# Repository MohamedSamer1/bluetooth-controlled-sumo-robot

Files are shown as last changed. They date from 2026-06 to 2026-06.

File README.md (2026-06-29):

<p align="center">
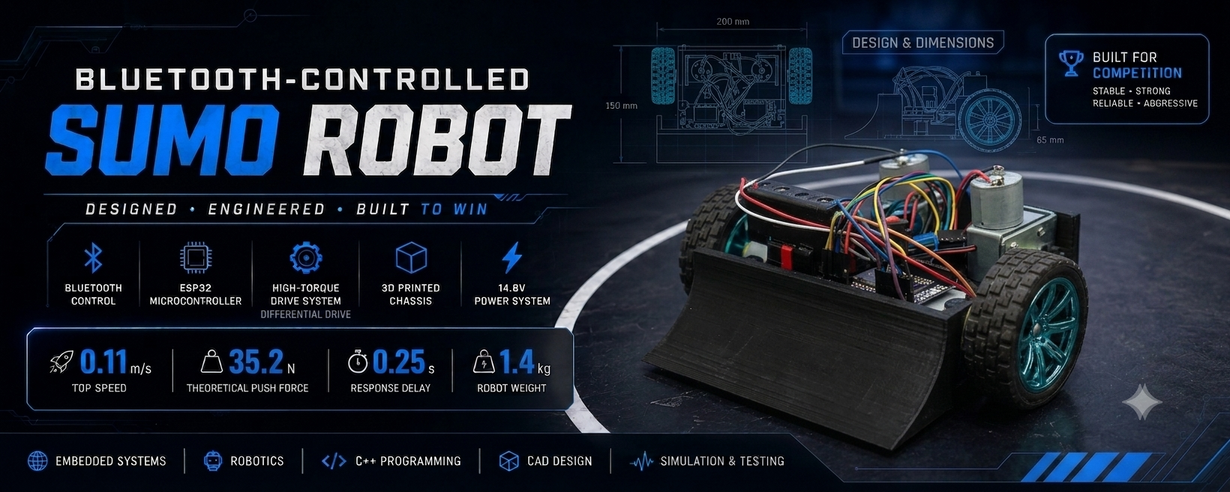
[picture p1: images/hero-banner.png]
Bluetooth-Controlled Sumo Robot
    
</p>

<h1 align="center">🤖 Bluetooth-Controlled Sumo Robot</h1>

<p align="center">
A high-performance ESP32-powered sumo robot engineered for competitive robotics.<br>
Designed through a complete engineering workflow spanning mechanical design,
embedded systems, electronics integration, mathematical modeling, and system validation.
</p>

<p align="center">









</p>

---

## 📑 Table of Contents

- [Project Overview](#-project-overview)
- [Design Objectives & Requirements](#-design-objectives--requirements)
- [System Architecture](#️-system-architecture)
- [Mechanical Design](#️-mechanical-design)
- [Electronics Design](#-electronics-design)
- [Control System & Software](#-control-system--software)
- [Engineering Calculations](#-engineering-calculations)
- [CAD Gallery](#️-cad-gallery)
- [Simulation & Validation](#-simulation--validation)
- [Final Prototype & Specifications](#-final-prototype--specifications)
- [Results & Lessons Learned](#-results--lessons-learned)
- [Challenges & Engineering Decisions](#-challenges--engineering-decisions)
- [Future Improvements](#-future-improvements)
- [Repository Structure](#-repository-structure)
- [References](#-references)
- [Team](#-team)
- [License](#-license)

---

## 📖 Project Overview

Sumo robotics combines mechanical engineering, embedded systems, electronics, and control theory to build robots capable of pushing opponents out of a circular arena while maintaining stability, traction, and responsiveness.

This project was developed for the **Mechatronics Design** course at **Modern Sciences and Arts University (MSA University)**. Rather than treating the build as a programming exercise alone, the team followed a full engineering design process — concept development, analytical calculations, CAD modeling, electronics integration, firmware development, simulation, manufacturing, and experimental testing — to produce a fully functional Bluetooth-controlled sumo robot.

**Project summary:**

- **Controller:** ESP32, communicating wirelessly with a smartphone over Bluetooth
- **Locomotion:** Differential drive using two independently controlled DC motors
- **Chassis:** Low-profile wedge design that maximizes pushing capability
- **Workflow:** Mechanical CAD (Inventor) → circuit design (Proteus/KiCad) → firmware (Arduino) → analytical modeling (MATLAB/Simulink) → physical assembly and testing

The final prototype achieved stable wireless control, fast motor response, and competitive maneuverability, meeting all project design objectives.

---

## 🎯 Design Objectives & Requirements

The goal was to design and manufacture a compact, reliable, high-performance Bluetooth-controlled sumo robot. This translated into the following engineering targets:

| Requirement | Goal |
|---|---|
| Bluetooth communication | Stable, low-latency link between phone and robot |
| Pushing force | Maximized without sacrificing stability |
| Center of gravity | Kept as low as possible |
| Footprint | Compact, arena-appropriate dimensions |
| Response time | Minimal delay between command and motion |
| Drive system | Reliable differential-drive control |
| Maintainability | Modular assembly for easy access/repair |
| Structure | Robust enough to withstand collision loads |

Every mechanical, electrical, and software decision in this project was evaluated against this table to keep the three subsystems working as one coherent mechatronic system.

---

## 🏗️ System Architecture

The robot is organized into four subsystems that map directly onto the signal/power flow from operator to motion:

```text
Smartphone → Bluetooth → ESP32 → Motor Driver → DC Motors → Robot Motion
```

| Subsystem | Contents |
|---|---|
| **Mechanical** | Custom CAD chassis, low-profile wedge, differential-drive wheel layout, optimized weight distribution |
| **Electrical** | ESP32 microcontroller, L298N motor driver, Li-ion battery pack, DC geared motors, Bluetooth module |
| **Software** | Arduino firmware, Bluetooth protocol handling, differential-drive control logic, PWM motor control |
| **Validation** | MATLAB calculations, Simulink modeling, Proteus circuit simulation, physical testing |

> 💡 **Engineering focus:** mechanical design, electronics, embedded programming, simulation, and validation were developed together — not bolted on sequentially — to produce a balanced, competitive platform.

---

## ⚙️ Mechanical Design

### Design Philosophy

Every mechanical component was chosen or shaped around three priorities: maximize pushing capability, keep the center of gravity low, and minimize weight without sacrificing rigidity.

### Chassis & Wedge

The chassis was modeled in **Autodesk Inventor** using a modular approach for easier manufacturing, assembly, and maintenance. Key considerations:

- Low-profile geometry that can slide underneath an opponent's chassis
- Compact footprint for maneuverability
- Symmetrical weight distribution
- Easy access to internal electronics
- Rigid construction to absorb impact loads

The front **wedge** — one of the most important parts on any sumo robot — is angled to lift the opponent's front wheels, reduce their traction, transfer pushing force efficiently into the chassis, and shield the robot from direct frontal impacts. The attack angle balances engagement against ground clearance during normal movement.

<p align="center">
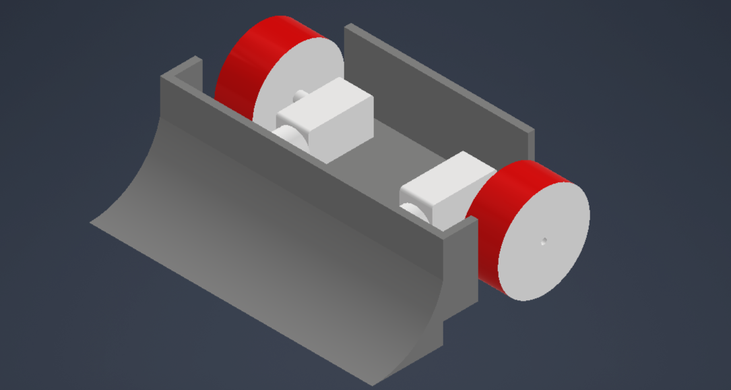
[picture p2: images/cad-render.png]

</p>

> **Figure 1:** Complete CAD assembly of the Bluetooth-Controlled Sumo Robot.

<p align="center">
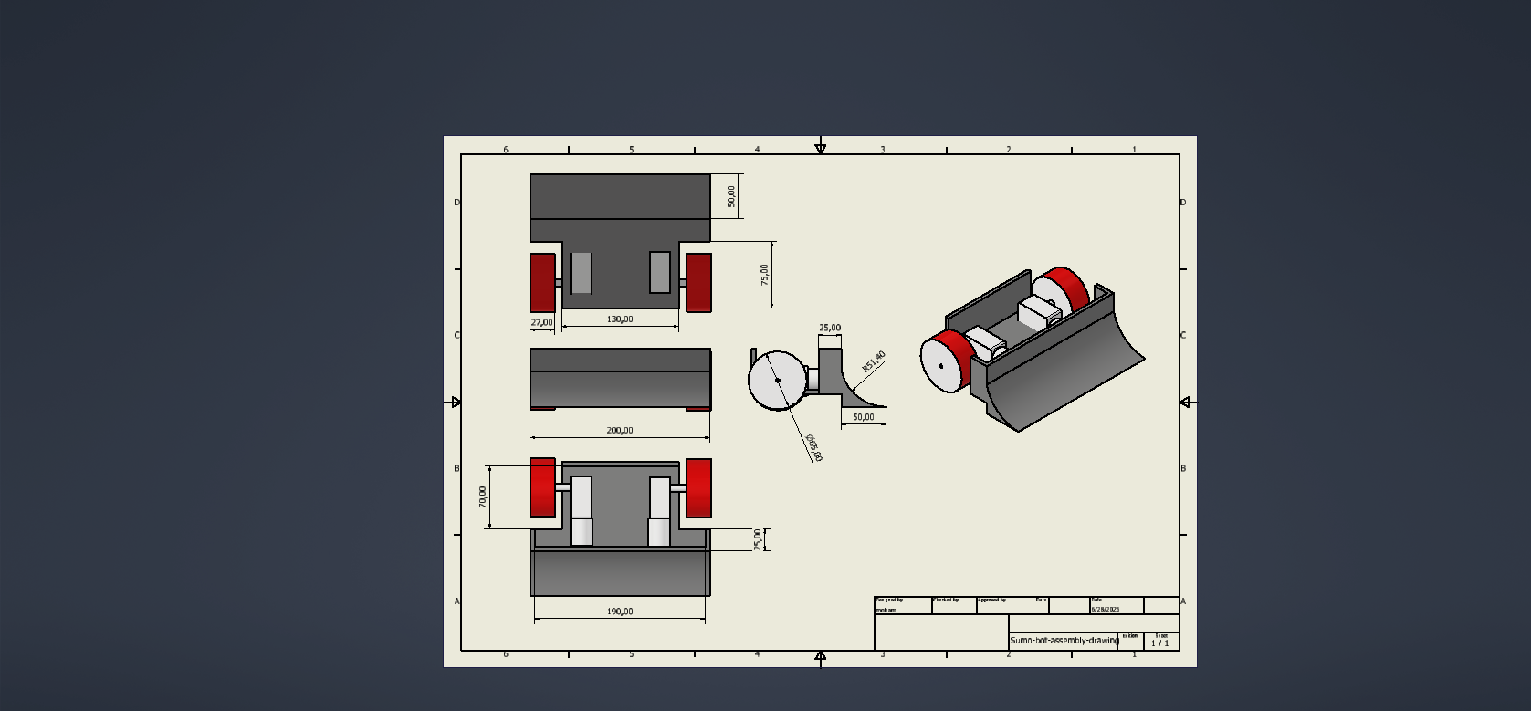
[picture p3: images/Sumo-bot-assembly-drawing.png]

</p>

### Wheel Configuration & Weight Distribution

The robot uses a **differential-drive** layout: two independently driven DC motors with high-traction wheels, plus one free-rotating caster wheel. This gives zero-radius turning, a simple control architecture, and reliable navigation inside the arena.

Weight distribution is just as critical as the drivetrain itself. The battery pack sits close to the drive wheels to increase normal force on the tires (improving traction and pushing force), and the heaviest components — motors and battery — are mounted as low as possible to keep the center of gravity down and improve stability during aggressive pushing.

<p align="center">
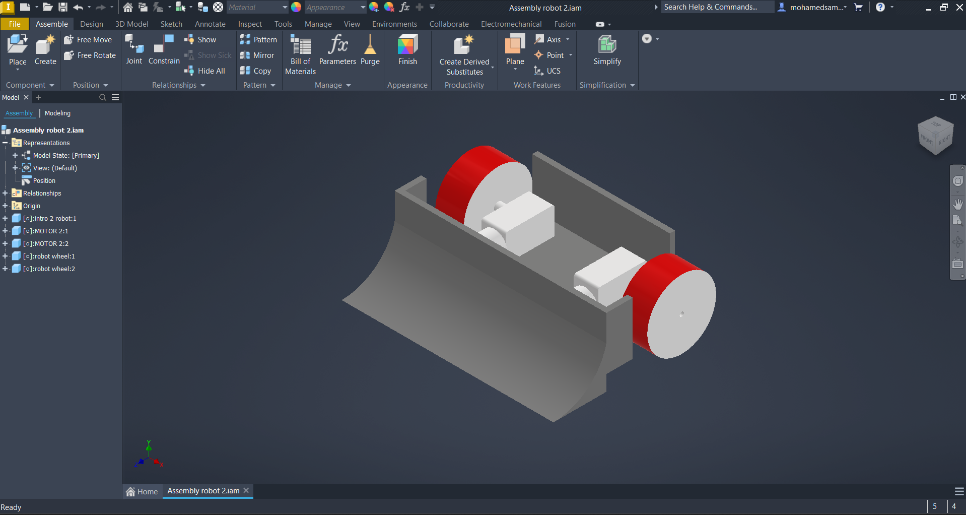
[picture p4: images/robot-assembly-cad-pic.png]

</p>

> **Figure 2:** Exploded view of the mechanical assembly.

---

## 🔌 Electronics Design

The electrical system covers four functions: control, power, motor drive, and communication.

| Component | Function |
|---|---|
| ESP32 | Main controller — reads Bluetooth input, generates PWM, coordinates drive logic |
| L298N Motor Driver | Bidirectional, PWM-based dual H-bridge motor control |
| DC Geared Motors | Robot propulsion |
| Li-ion Battery Pack | Power supply |
| Bluetooth Module | Wireless link to smartphone |

```text
Smartphone → Bluetooth → ESP32 Controller → L298N Motor Driver → Battery-supplied Motors
```

**ESP32:** chosen for its built-in Bluetooth, ample processing headroom, low power draw, multiple PWM outputs, and mature Arduino ecosystem support. It handles Bluetooth command parsing, PWM generation, motor direction control, and differential-drive coordination.

**Motor driver (L298N):** provides bidirectional control, PWM speed regulation, independent left/right channels, and high-current switching for both motors.

**Power system:** a rechargeable Li-ion pack sized to deliver stable voltage and sufficient current under heavy motor load, including the high startup current draw typical of DC motors. Sizing was checked analytically before parts were ordered (see [Engineering Calculations](#-engineering-calculations)).

**Circuit design:** the control circuit was first built and verified in **Proteus** to validate wiring and motor-control logic, then the schematic and PCB layout were finalized in **KiCad**.

<p align="center">
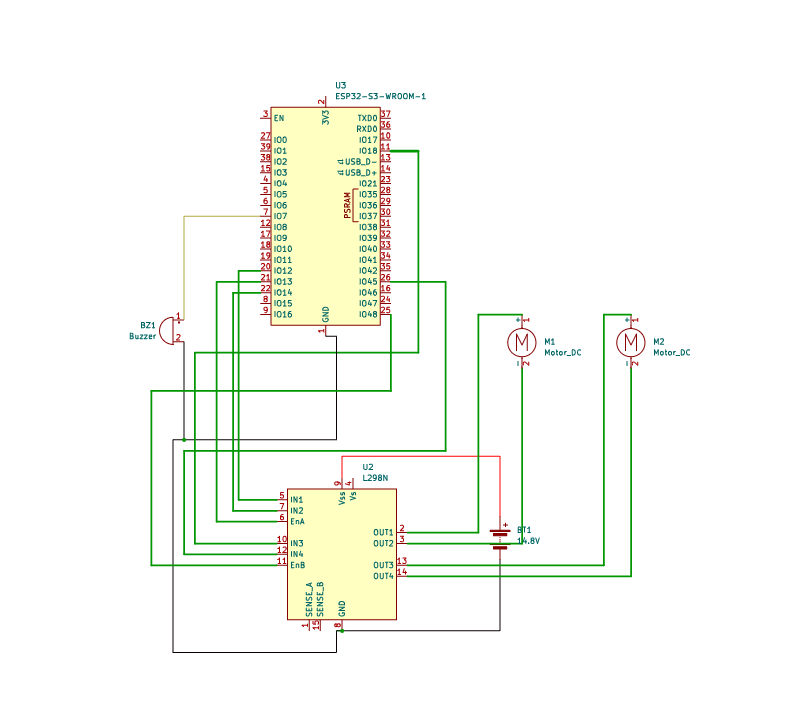
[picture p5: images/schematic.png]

</p>

> **Figure 3:** Electrical schematic of the control system.

---

## 🧠 Control System & Software

### Differential Drive Logic

The operator sends movement commands from a smartphone app over Bluetooth. The ESP32 parses each command and generates the matching PWM signals for the left and right motors:

| Left Motor | Right Motor | Resulting Motion |
|---|---|---|
| Forward | Forward | Forward |
| Reverse | Reverse | Backward |
| Forward | Reverse | Rotate right |
| Reverse | Forward | Rotate left |
| Stop | Stop | Stop |

### Firmware Architecture

Built in the **Arduino IDE** with a modular structure for readability, debugging, and future expansion:

```text
Initialize hardware → Connect Bluetooth → Receive command →
Process input → Generate PWM → Drive motors → Wait for next command
```

**Key features:**
- Wireless Bluetooth operation with low-latency response
- Differential-drive control algorithm
- PWM-based motor speed control
- Non-blocking firmware structure to keep communication responsive
- Modular code, ready for autonomous-navigation features later

---

## 📐 Engineering Calculations

Before any manufacturing began, the team ran the analytical work needed to size components correctly rather than relying on trial and error:

- Motor torque estimation
- Pushing-force analysis
- Robot velocity estimation
- Battery capacity and power-consumption calculations
- Differential-drive kinematics

These results directly drove the choice of motors, gear ratio, battery capacity, and overall mechanical layout. Full derivations are in **[`docs/Project_Report.pdf`](docs/Project_Report.pdf)**.

---

## 🖼️ CAD Gallery

The full robot was modeled in **Autodesk Inventor** before any physical fabrication, allowing the team to check component placement, weight distribution, assembly constraints, and manufacturability up front.

<p align="center">

</p>

> **Figure 4:** Complete CAD assembly.

<p align="center">
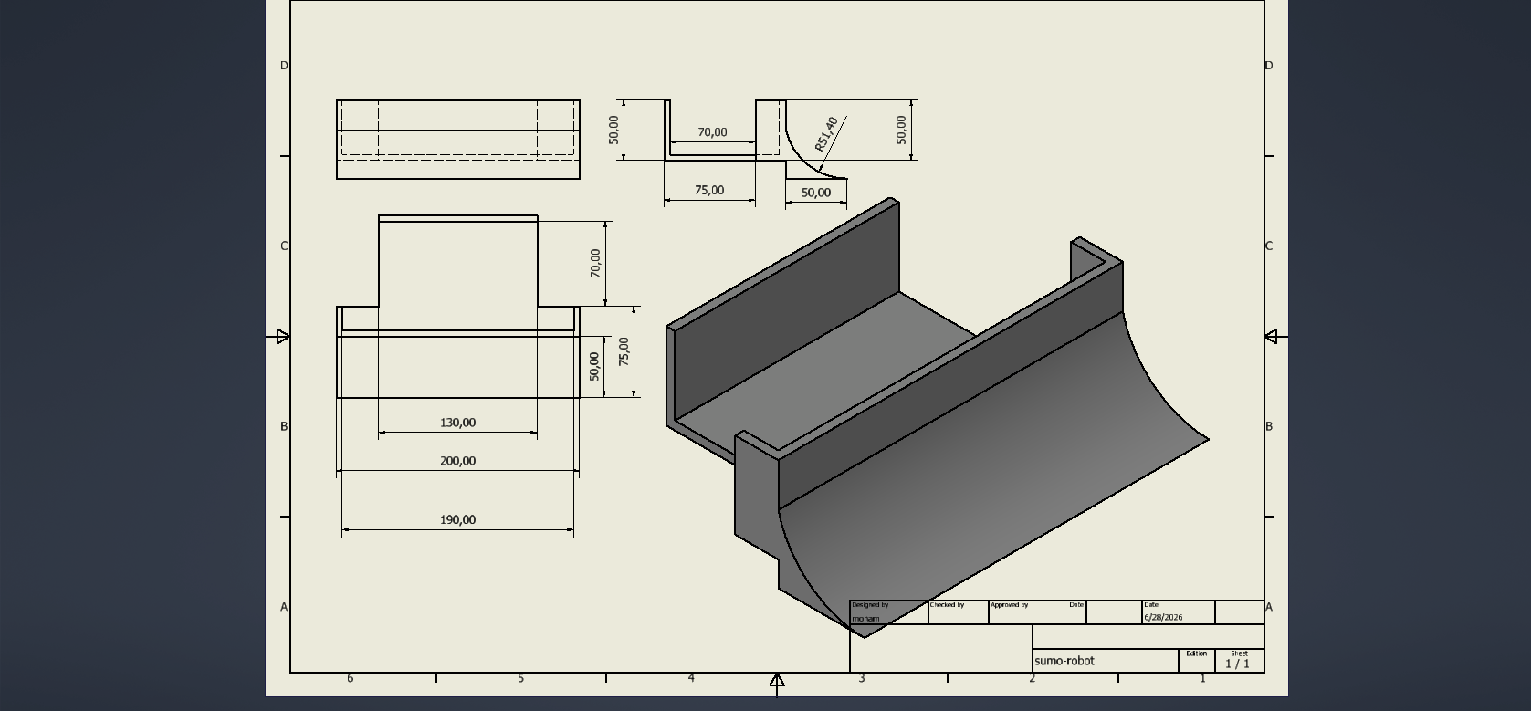
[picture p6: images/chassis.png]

</p>

> **Figure 5:** Chassis design — built for rigidity, low weight, and easy maintenance.

<p align="center">
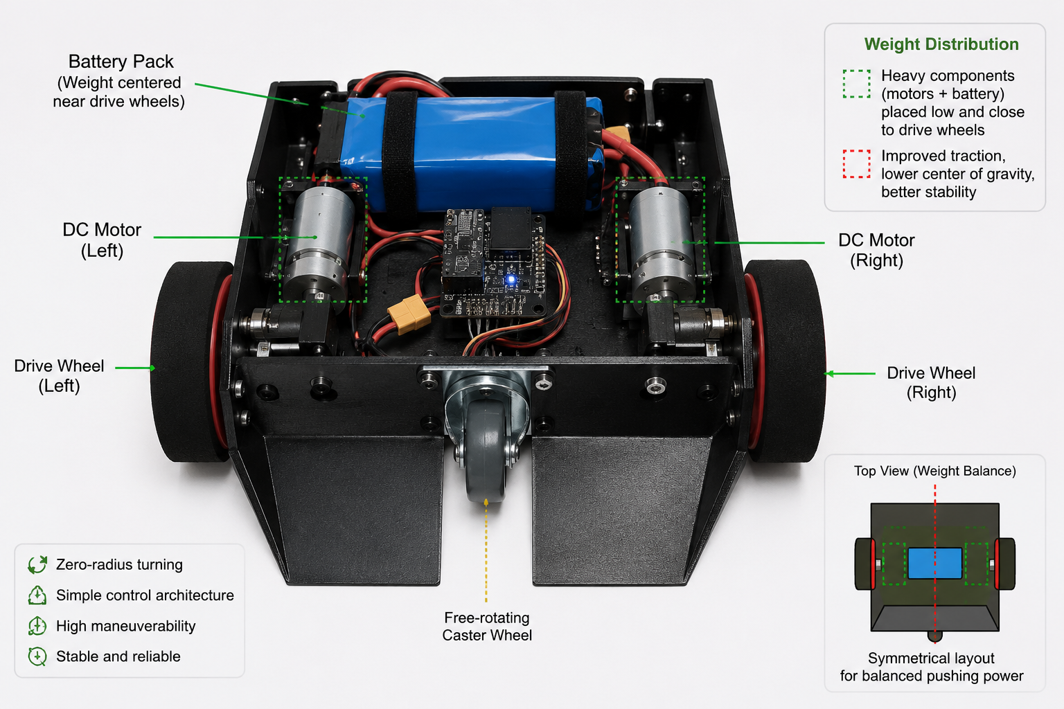
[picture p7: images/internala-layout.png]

</p>

> **Figure 6:** Internal electronics layout — planned to reduce cable clutter, improve accessibility, and keep weight balanced.

---

## 🧪 Simulation & Validation

### MATLAB & Simulink

Used to model the robot's dynamic behavior — differential-drive kinematics, motion response, and velocity estimation — and to cross-check the hand calculations above.

<p align="center">
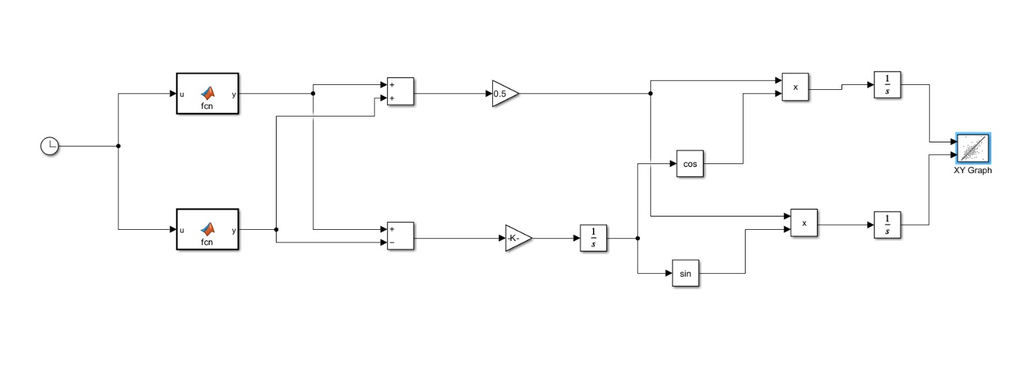
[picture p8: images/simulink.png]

</p>

> **Figure 7:** Simulink model used for system analysis.

### Proteus Simulation

The electronic control system (motor driver behavior, ESP32 control logic, wiring) was validated in **Proteus** before any hardware was assembled, catching circuit issues early and reducing rework.

<p align="center">
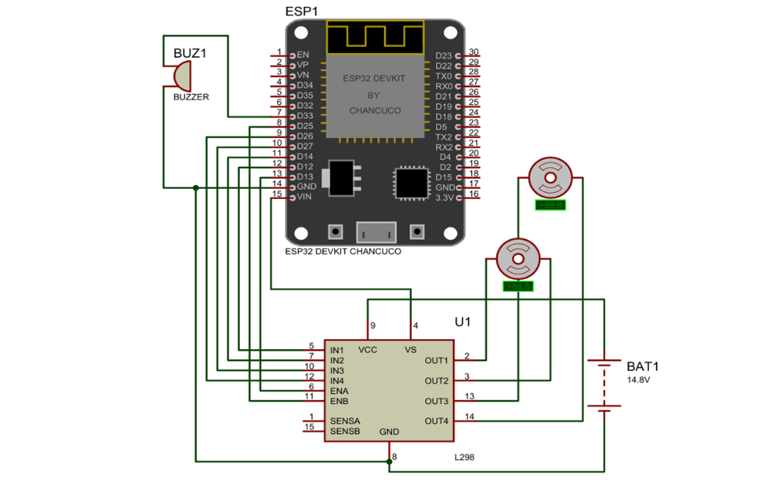
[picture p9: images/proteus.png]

</p>

> **Figure 8:** Proteus simulation of the electronic system.

---

## 🤖 Final Prototype & Specifications

After design, simulation, and validation were complete, the robot was manufactured and assembled into a fully functional prototype integrating all mechanical, electrical, and software subsystems.

<p align="center">
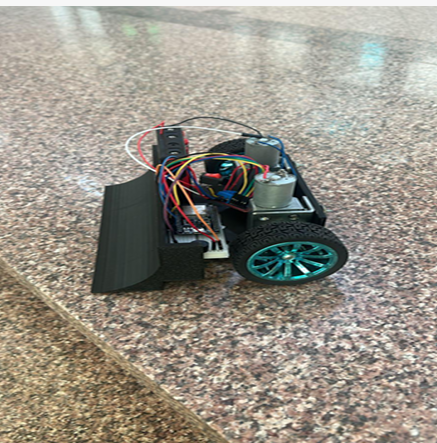
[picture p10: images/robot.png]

</p>

> **Figure 9:** Final assembled robot.

| Specification | Value |
|---|---:|
| Controller | ESP32 |
| Drive System | Differential drive |
| Communication | Bluetooth |
| Battery | 14.8V Li-ion |
| Motor Driver | L298N |
| Chassis | 3D printed |
| CAD Software | Autodesk Inventor |
| Simulation | MATLAB / Simulink |
| Circuit Validation | Proteus |
| **Top Speed** | **0.11 m/s** |
| **Theoretical Push Force** | **35.2 N** |
| **Response Delay** | **0.25 s** |
| **Robot Weight** | **1.4 kg** |

---

## 📊 Results & Lessons Learned

### Achievements

- ✅ Stable Bluetooth communication with low latency
- ✅ Responsive, stable differential-drive motion
- ✅ Compact, lightweight chassis with good traction
- ✅ Reliable electronic integration under motor load
- ✅ Simulation results consistent with physical testing

### Lessons Learned

- Mechanical and electrical systems need to be designed together, not in isolation — chassis geometry directly affects power and traction needs.
- Weight distribution has an outsized effect on pushing performance and stability.
- Simulating before manufacturing catches design errors early and saves rework.
- A modular firmware architecture made debugging and later changes much easier.
- Doing the analytical calculations up front, rather than after building, improved reliability and cut development time.

<p align="center">

| CAD Design | Prototype |
|---|---|
|  |  |

</p>

---

## 🚧 Challenges & Engineering Decisions

**Weight vs. traction:** more weight improves traction and pushing force but increases demands on motors and battery. The team kept the chassis lightweight overall while concentrating mass directly above the drive wheels — getting traction benefits without the full weight penalty.

**Center of gravity:** an elevated CG hurts stability during pushing contests. Mounting the battery and motors low and distributing mass symmetrically kept the robot stable during aggressive maneuvers.

**Startup current:** DC motors draw far more current at startup than during steady-state operation, so the battery and motor driver had to be sized for peak draw, not average draw, to guarantee reliable starts and stable voltage.

**Bluetooth responsiveness:** keeping the link responsive while continuously updating motor outputs required non-blocking firmware that avoids delays in the main control loop.

**Key decisions:**
- Differential drive chosen for simplicity and maneuverability over more complex steering systems
- ESP32 chosen specifically for integrated Bluetooth (avoiding a separate wireless module)
- CAD-first workflow adopted to catch manufacturing issues before cutting material
- Simulation completed before assembly to validate behavior ahead of physical testing

---

## 🚀 Future Improvements

| Area | Planned Enhancements |
|---|---|
| **Mechanical** | Aluminum/carbon-fiber chassis, improved wheel materials, adjustable wedge geometry, further weight reduction |
| **Electronics** | Custom PCB, higher-efficiency motor driver, battery monitoring, integrated voltage regulation |
| **Software** | PID speed control, closed-loop motor feedback, automatic braking, configurable drive modes |
| **Autonomy** | Ultrasonic/IR sensors, computer vision, line detection, obstacle avoidance, ROS 2 integration, autonomous opponent detection |

---

## 📁 Repository Structure

```text
bluetooth-controlled-sumo-robot
│
├── README.md
├── LICENSE
│
├── cad/
│   ├── MOTOR.dwg
│   ├── MOTOR.ipt
│   ├── robot-wheel.dwg
│   ├── robot-wheel.ipt
│   ├── Sumo-bot-assembly-drawing.dwg
│   ├── sumo-robot-body.ipt
│   └── sumo-robot.dwg
│
├── electronics/
│   ├── schematic.pdf
│   └── wiring.png
│
├── firmware/
│   ├── code/
│   ├── sumo-bot-code.ino
│   └── bluetooth-controlled-sumo-robot-simulink.slx
│
├── images/
│   ├── hero-banner.png
│   ├── cad-render.png
│   ├── chassis.png
│   ├── internala-layout.png
│   ├── MOTOR.png
│   ├── proteus.png
│   ├── robot-assembly-cad-pic.png
│   ├── robot-wheel.png
│   ├── robot.png
│   ├── schematic.png
│   ├── simulink.png
│   └── Sumo-bot-assembly-drawing.png
│
└── docs/
    └── Project_Report.pdf
```

| Directory | Description |
|---|---|
| `cad/` | Autodesk Inventor parts and drawing files |
| `electronics/` | Schematic (PDF) and wiring diagram |
| `firmware/` | ESP32 Arduino code and Simulink model |
| `images/` | CAD renders, prototype photos, and diagrams |
| `docs/` | Project report and supporting calculations |

---

## 📚 References

- ESP32 Technical Documentation
- Arduino Documentation
- Autodesk Inventor Documentation
- MATLAB & Simulink Documentation
- KiCad Documentation
- Proteus Documentation

Full derivations and design methodology are documented in **[`docs/Project_Report.pdf`](docs/Project_Report.pdf)**.

---

## 📄 License

Released under the **MIT License** — see [LICENSE](LICENSE) for details.

---

## ⭐ Support

If this project was useful or interesting:

- ⭐ Star this repository
- 🍴 Fork it and build your own version
- 💡 Open an issue with feedback or questions
- 🤝 Connect on LinkedIn

<p align="center">

### Built with ❤️ by Mohamed Samer
 **Mechatronics Engineering Student** · Modern Sciences and Arts University (MSA University)
 
 https://mohamed-samer.vercel.app/

</p>

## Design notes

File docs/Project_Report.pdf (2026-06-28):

# MSA

October University for Modern Sciences and Arts Faculty of Engineering
Department of Mechatronics System Engineering

# SUMO ROBOT

Prepared By

Jason Sameh Zarref | ID: 251086
Youssef Mohamed Mostafa | ID: 255000
Felobateer Akram Fawzi | ID: 255231
Ibrahim Wael Abdelmonem | ID: 251112
Mohamed Ahmed Imam | ID: 253440
Mohamed Samer | ID: 253335
Haneen Ahmed Nabih | ID: 251417

Supervisor
Dr. Amgad M. Bayoumy

SUMO Robot — Project Report

## Table of Contents

## Chapter 1: Introduction

### 1.1 Background

In recent years, robotics has become an increasingly accessible field due to advancements in microcontrollers, wireless communication, and compact power solutions. Educational and hobbyist robotics projects have gained popularity in academic environments and maker communities worldwide.

The SUMO Robot is a mobile robotic system designed to demonstrate fundamental principles of embedded systems, wireless control, and mechatronics integration. The core of the robot is an ESP-series microcontroller that processes input, executes control logic, and communicates with external devices. Acting as the intermediary between the microcontroller and physical motion is a motor driver, which supplies controlled current to two DC motors mounted on a two-wheel drive platform.

The power supply consists of four 3.7 V batteries connected to provide reliable voltage and current necessary for motor and controller operation. This combination of hardware allows the robot to move, respond to commands, and serve as a practical tool for learning and experimentation in robotics design.

### 1.2 Problem Definition

Despite the growing interest in robotics education, many existing mobile robotic kits are either overly expensive or lack flexibility for customization and real-world experimentation. Learners and hobbyists often encounter challenges when integrating wireless communication, motor control, and power management on a single platform. Specifically, problems include:

- Limited control precision: standard robot kits may not allow programmable control using open-source environments.
- Power inefficiency: some designs fail to provide stable power, leading to reduced motor performance or controller resets.
- Lack of integration: communication modules and motor control components are not always designed to work together seamlessly.
The SUMO Robot project addresses these issues by combining an ESP microcontroller, a dedicated motor driver, and a suitable battery system to create an affordable, adaptable, and efficient mobile robotic platform.

### 1.3 Functional Requirements

The SUMO Robot is designed to perform the following functions:

1. Wireless Command Reception — the robot must receive movement commands (e.g., forward, backward, turn) via a wireless interface supported by the ESP microcontroller.
2. Motor Control — the system must drive two DC motors using the motor driver, translating control signals into motion with appropriate direction and speed.
3. Stable Power Delivery — the battery pack must supply sufficient voltage and current to both the ESP controller and the motors without significant voltage drop during operation.

4. Directional Movement — the robot must be able to move forward, backward, turn left, and turn right using differential wheel control.
5. Robust Mechanical Design — the two-wheel drive base must support the robot's weight and maintain balance during motion.

### 1.4 Project Specification

Component | Specification
Controller | ESP-series microcontroller (e.g., ESP32 / ESP8266)
Motor Driver | Dual-channel motor driver (compatible with 2 DC motors)
Motors | 2 × DC motors (rated for low-voltage operation)
Wheels | 2 × compatible wheels
Power Supply | 4 × 3.7 V rechargeable batteries (lithium-ion or LiPo)
Communication | Wi-Fi / Bluetooth (based on the ESP module used)
Chassis | Lightweight platform supporting all components
Control Interface | Mobile app, web interface, or remote controller
Operating Voltage | Approx. 14.8 V (with appropriate regulation for ESP and motor driver)

Note: if needed, a voltage regulator or DC-DC converter can be used to match the ESP's operating voltage requirements.

### 1.5 Current Technology

Robotics platforms today range from simple educational kits to advanced autonomous systems. Common solutions in the current field include:

- Arduino-based robots: widely used in education, these robots use Arduino microcontrollers with basic motor shields for motion control. They are simple but can be limited in wireless capabilities without additional modules.
- Raspberry Pi robots: with a single-board computer at their core, these robots can perform complex processing and vision tasks but are often bulkier and require more power.
- ESP-controlled robots: the rise of ESP microcontrollers (such as ESP32 and ESP8266) has enabled low-cost robotic platforms with integrated Wi-Fi and Bluetooth, making remote control and IoT integration easier. They strike a balance between processing capability, power consumption, and connectivity.
- Commercial kits: products such as LEGO Mindstorms and VEX offer modular designs but at a higher cost and with limited openness for custom hardware/software extension.

Compared with these technologies, the SUMO Robot leverages the strengths of the ESP ecosystem, efficient power configuration, and a simple drive system to offer a flexible and affordable mobile platform suitable for learning, prototyping, and experimentation.

## Chapter 2: System Design

### 2.1 Discussion of Design

A DC motor was selected as the actuator for this project because it offers high starting torque, precise speed control, a compact size, and good performance across a range of load conditions.

An ESP32 was chosen as the microcontroller due to its low cost, high-performance dual-core processing, and built-in Bluetooth and Wi-Fi modules for wireless connectivity.

The system architecture connects the voltage source to the motor driver, which in turn supplies the two motors. The ESP32 microcontroller is connected wirelessly to a mobile phone, which sends the movement commands.

A 3D-printed chassis was used for the robot body. Although 3D printing costs more than a standard robot chassis, the resulting structure is significantly stronger. Similarly, rechargeable batteries were chosen over standard batteries; although more expensive upfront, they can be reused many times, making them more cost-effective over the project's lifetime.

### 2.2 Design Specification

Electrical

Operating voltage: 14.8 V. Battery life for the four batteries: approximately 20–30 minutes of continuous operation.

Mechanical

Footprint: 15 cm × 20 cm. Total weight: up to 1.5 kg.

Software

Bluetooth response time: between 40 ms and 150 ms. Programming language: C++.

### 2.3 System Outline

The robot's control architecture follows the signal path shown below: the mobile phone and the motor driver both feed information to the ESP32 controller, which processes this input and issues commands to the DC motors (the actuators). The motors then produce the physical output — the robot's motion.

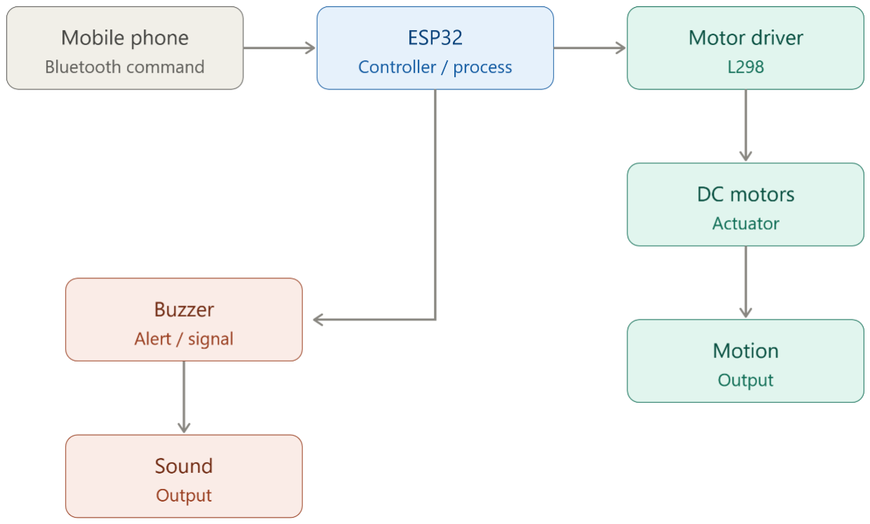
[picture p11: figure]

Figure 2.1 — System-level signal and control flow

## Chapter 3: Mechanical Design

The mechanical design of the robot is built around a differential-drive system powered by two high-torque DC motors. The chassis design prioritizes a low center of gravity and high traction to meet the requirements of the Sumo class.

### 3.1 Mechanical Design Calculations

The selection of the drive system was based on the need for high pushing torque and the ability to resist being pushed by opponents. The robot uses two miniature worm-gear DC motors rated at 12 V, with a gear ratio of 1:40 and a wheel diameter of 65 mm.

### 3.1.1 Torque and Pushing Force Analysis

The theoretical pushing force was calculated to confirm that the robot can overcome the friction of the dohyo (ring) and push opponents.

Motor specifications:

- Initial torque (TInitial) = 6.4 kg·cm
- Wheel radius (r) = 32.5 mm = 0.0325 m First, the torque is converted to SI units (newton-metres):

T_Initial = 6.4 kg·cm × 0.098 = 0.628 N·m T_Total = 2 × 0.628 = 1.256 N·m

The theoretical linear pushing force is then:

F_Push = T_Total ÷ r = 1.256 N·m ÷ 0.0325 m ≈ 38.6 N

So, the robot can push an opposing sumo robot of approximately 3 kg.

### 3.2 Mathematical Modeling

To implement precise control in the software, a mathematical model of the differential-drive system was established. This model relates the inputs (left and right wheel velocities) to the robot's pose in the global frame.

### 3.2.1 Differential Drive Kinematics

The robot's motion is defined by its position (x, y) and orientation (θ). The kinematic equations for the differential-drive system are derived below.

Let VR and VL be the linear velocities of the right and left wheels, and let L be the track width (the distance between the wheel centres).

Linear velocity of the robot (V):

V = (vR + vL) / 2

Angular velocity of the robot (ω):

The rate of rotation is determined by the difference in wheel speeds divided by the track width (L):

ω = (vR − vL) / L

## Chapter 4: Electrical Design

This chapter presents the electrical design of the proposed system and explains how electrical power is generated, distributed, and utilized to ensure proper system operation. It focuses on the selection of electrical components, the configuration of the power supply, and the calculations required to guarantee reliable and safe performance.

The electrical system plays a critical role in operating the control unit and driving the DC motors through a suitable motor driver. Special consideration is given to both normal operating conditions and peak-load situations, such as motor startup and stall conditions, to ensure that all components function within their specified limits and that the overall system operates efficiently and safely.

### 4.1 Power Supply Calculations

Battery Configuration

The system is powered using four lithium-ion batteries, each with a nominal voltage of 3.7 V. The batteries are connected in series to increase the total output voltage. The resulting nominal supply voltage is:

V_total = 3.7 V × 4 = 14.8 V

Voltage Regulation

The DC motors are rated for 12 V, but the L298 motor driver typically introduces a voltage drop of around 2–4 V; the motors therefore operate close to their rated capability rather than at the full battery voltage. The ESP32 operates at 3.3 V internally but accepts a 5 V input and regulates it internally.

Current and Power Requirements

The current consumption of the electrical components is estimated based on datasheet values and typical operating conditions.

Motor current (normal operation). Each DC motor has a rated current of 0.3 A at 12 V. Since two motors are used:

I_motors = 0.3 A × 2 = 0.6 A

The rated electrical power consumed by the motors is:

P_motors = V × I = 12 V × 0.6 A = 7.2 W

Motor current (stall condition). The stall current of each motor is 2 A. Under worst-case conditions:

I_stall = 2 A × 2 = 4 A

The maximum power drawn during stall conditions is:

P_stall = 12 V × 4 A = 48 W

Stall conditions are considered transient and are avoided during normal operation through appropriate control logic.

ESP32 and logic circuit consumption. The ESP32 microcontroller draws a current of approximately 240 mA during normal operation. The L298 motor driver also requires a small current for its internal logic circuits, approximately 40 mA. The total current required by the control and logic circuits is therefore:

I_logic = 0.24 A + 0.04 A = 0.28 A

This current is supplied through a regulated low-voltage power source to ensure stable and reliable operation of the control electronics.

Total Current Requirement

Under normal operating conditions:

I_total = I_motors + I_logic = 0.6 A + 0.28 A = 0.88 A

Applying a safety factor of 30%:

I_required = 0.88 A × 1.3 ≈ 1.15 A

The battery pack and power-distribution system are therefore designed to safely supply currents exceeding this value.

### 4.2 Electrical and Electronics Calculations

The DC motor is the main actuator in this system. To control the motor's speed and direction, an L298 dual H-bridge motor driver is used as the interface between the ESP32 microcontroller and the DC motors.

Section 4.1 established the system's current and power budget from first principles. This section verifies that the selected L298 driver can meet that budget at the component level.

From the motor datasheet, the rated current of each motor under normal load is 0.3 A at 12 V, giving a combined rated current of 0.6 A and a rated power of 7.2 W (as calculated in Section 4.1). Under stall conditions, each motor draws up to 2 A, giving a combined stall current of 4 A and a peak power draw of 48 W.

The L298 motor driver is rated to supply a maximum continuous current of 2 A per channel. Since each motor is driven on its own channel, the driver comfortably meets the 0.3 A normal-operation requirement per motor, and can also tolerate the 2 A per-motor stall current for short durations without exceeding its rated limit. Continuous operation at stall current is avoided in the control logic to prevent overheating and long-term damage to the driver.

Combined with the ESP32's 240 mA draw, the total system current requirement of approximately 0.88 A (1.15 A with a 30% safety margin, as derived in Section 4.1) falls well within the supply capability of the four-cell 14.8 V battery pack regulated through the L298 driver.

## Chapter 5: Control Design

The control design of the differential-drive sumo robot defines how sensory information is processed and translated into motor commands to achieve stable, responsive, and competitive motion. The robot follows a differential-drive configuration, where two independently driven wheels allow linear and rotational movement through velocity control. The control system integrates mathematical modeling, algorithm development, and mechatronic simulation to validate system performance before physical implementation. Detailed calculations, parameter tuning, and implementation code are provided in the appendices.

### 5.1 Simulation of Mathematical Modeling (Simulink)

The mathematical model of the differential-drive sumo robot was developed to describe the kinematic behaviour of the system and to predict its motion under various control inputs. The model is based on the differential-drive kinematics derived in Section 3.2, where the robot's linear and angular velocities are functions of the left and right wheel angular velocities.

Using MATLAB/Simulink, a dynamic simulation environment was created to represent the robot's motion in a two-dimensional plane. The model incorporates wheel radius, wheelbase distance, motor angular velocity, and robot orientation. By simulating different velocity inputs, the robot's forward motion, turning behaviour, and rotational response were analysed.

The Simulink model enabled verification of the control strategy by observing position, orientation, and velocity responses over time. This simulation step ensured that the control logic produced stable motion and correct turning behaviour before implementation in hardware.

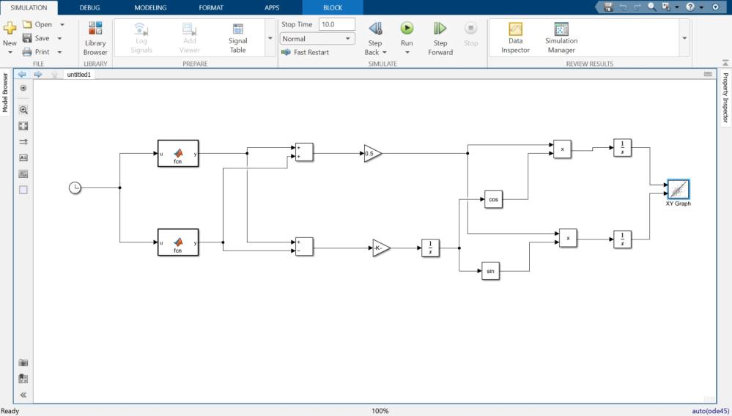
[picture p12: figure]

Figure 5.1 — Simulink block diagram of the differential-drive kinematic model

### 5.2 Control Algorithm (Flowchart)

The control algorithm governs the robot's decision-making process and movement strategy during operation. It is designed to process Bluetooth command input, determine the robot's current state, and generate the appropriate motor commands for navigation and opponent interaction.

The algorithm begins with system initialization, followed by continuous polling for an incoming Bluetooth command. Once a command is received, conditional logic determines whether the robot should move forward, move backward, or turn, and motor speed and direction are updated accordingly to achieve the desired motion.

A flowchart representation was used to clearly define the logical sequence and decision branches of the control algorithm, improving clarity, debugging, and future modification. The complete flowchart is shown below, and the corresponding implementation is provided in Appendix D.

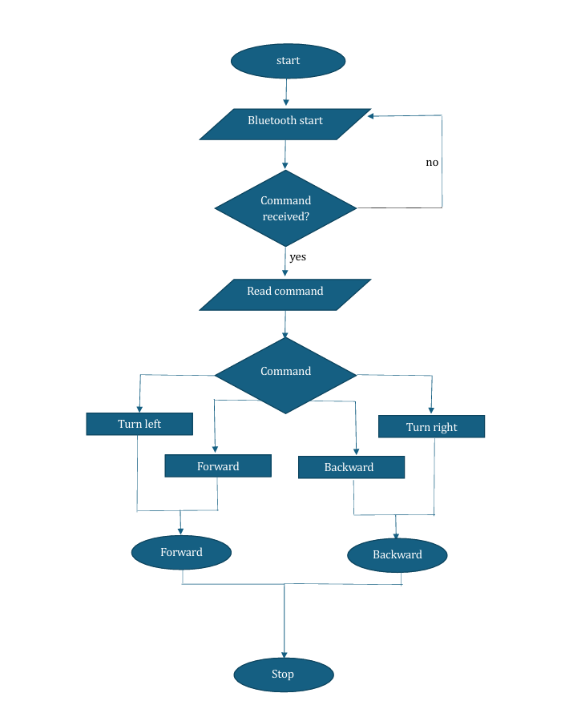
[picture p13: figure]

Figure 5.2 — Control algorithm flowchart for Bluetooth command handling

### 5.3 Mechatronics Simulation (Proteus)

Mechatronic simulation was carried out using Proteus to validate the integration of electronic components and control logic. The simulation environment included the microcontroller, motor driver, DC motors, and power supply, allowing the system to be tested virtually as a complete unit.

Proteus simulation enabled verification of signal flow between the microcontroller and actuators, ensuring correct motor driver operation and proper response to control signals. It also allowed observation of voltage levels, motor behaviour, and system timing under different control conditions.

By simulating the circuit and embedded control program prior to physical construction, potential hardware and software issues were identified and resolved early in the design process. The circuit schematic is provided in Appendix C.

## Chapter 6: Results and Discussion

The Sumo Robot has a total mass of approximately 1.5 kg and dimensions of 15 cm × 20 cm. The robot is manually controlled using an ESP32 microcontroller connected to a Bluetooth car-controller app, two DC worm-gear motors, a motor driver, two wheels of 65 mm diameter, and a 3D-printed body.

### Maximum Robot Speed

The maximum linear speed of the robot depends on the motor speed and wheel diameter. The robot speed is calculated using:

V = (RPM × π × D) / 60
V = (32 × 3.14 × 0.065) / 60 V = 0.109 m/s

The maximum robot speed is approximately 0.11 m/s, which provides controlled and stable motion suitable for manual Sumo Robot operation.

### Response Delay Analysis

The total response delay of the robot is the sum of the wireless communication delay, microcontroller processing time, motor driver response, and motor mechanical response:

total delay = wireless delay + processing delay + driver delay + motor delay total delay = 0.10 + 0.02 + 0.03 + 0.10 = 0.25 s

The response delay is approximately 0.25 seconds, which allows fast and reliable manual control.

### Pushing Capability

Although the motors provide high torque (40 kg·cm), the maximum pushing force of the robot is limited by wheel-to-ground traction, which mainly depends on robot weight. The maximum pushing force is given by:

F_max = g × mass × μ
F_max = 9.81 × 1.5 × 0.5
F_max ≈ 7.36 N

This force corresponds to pushing an opposing mass of approximately 1.5 kg.

Real Pushing Test

In a real pushing test, the robot was unable to push a 7 kg object, and its wheels began to slip. The force required to push a 7 kg object is:

F_required = 9.81 × 7 × 0.5 = 43.3 N

Since the robot can only generate 7.36 N — roughly a fifth of the 43.3 N required — the wheels lost traction and slipped well before the object could be moved.

### Discussion

The results show that robot performance is mainly limited by traction rather than motor torque. The calculated speed and response delay are both well suited to manual control, while pushing capability could be improved by increasing the robot's weight or wheel friction. Although the motors provide high torque, the actual pushing force of the robot is constrained by its weight and the wheel-to-ground traction available, not by the motors themselves.

To increase pushing capability, the following solutions can be applied:

- Increase robot weight.
- Improve wheel friction (better tyres).
- Optimize weight distribution over the wheels.
These improvements would allow the robot to push heavier opponents more effectively during Sumo matches. Overall, the experimental results are consistent with the theoretical calculations.

## Chapter 7: Conclusions and Future Work

### 7.1 Conclusions

The design is successful due to its excellent stability and strong structural integrity. The robust 3D-printed chassis provides high resistance to external forces, making the robot difficult to push during competition. Additionally, the compact structure and low center of gravity improve balance and prevent tipping during collisions. Overall, the design performs reliably under the given constraints and meets the project requirements.

### 7.2 Recommendations

Future enhancements could focus on:

- Improved opponent detection: integrating distance sensors or vision-based systems, such as cameras or LiDAR, to enhance awareness of the opponent's position.
- Enhanced mobility and power: using higher-torque motors to increase pushing capability and overall movement efficiency.
- Better traction and stability: employing wheels with stronger grip and higher friction to improve ground adherence and prevent slipping during matches.

## Appendix A: Project Outline Details

### Electronics Subsystem

- ESP32 (microcontroller)
- L298 motor driver
- Breadboard, 400 tie-point
- Battery charger, 1-cell, 3.7 V
- Switch
- Jumper wires

### Mechanical Subsystem

- JGY-370-1258 miniature gear motor, 12 V
- Robot wheels (rubber tyres)
- 3D-printed chassis

## Appendix B: Mechanical Drawings

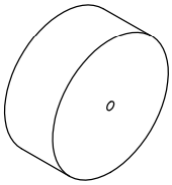
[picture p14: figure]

Robot Wheel

JGY-370-1258 Miniature Gear Motor, 12 V

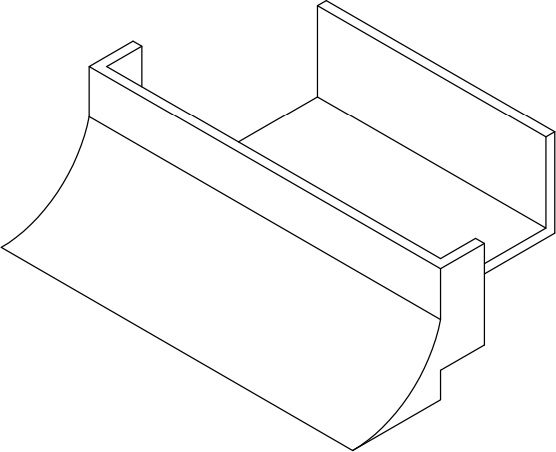
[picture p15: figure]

3D-Printed Chassis

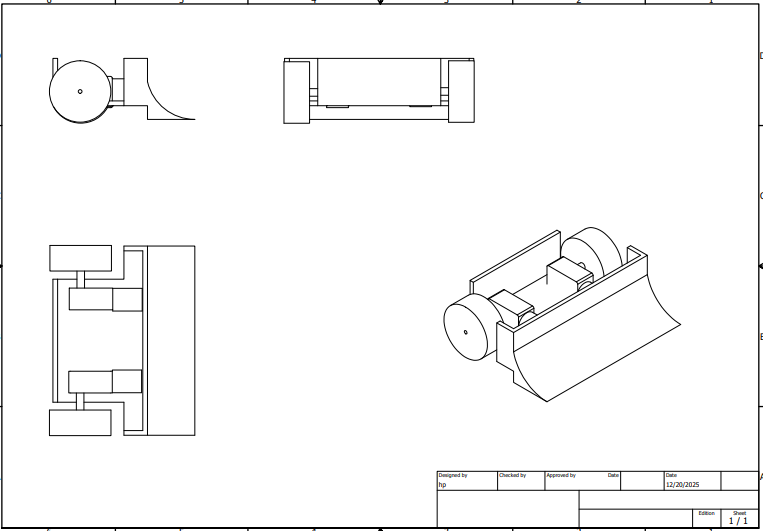
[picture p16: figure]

Full Assembly — Orthographic and Isometric Views

## Appendix C: Electrical Drawings

The full circuit schematic below shows the wiring between the ESP32 DevKit, the L298 motor driver, the two DC motors, the buzzer, and the 14.8 V battery pack.

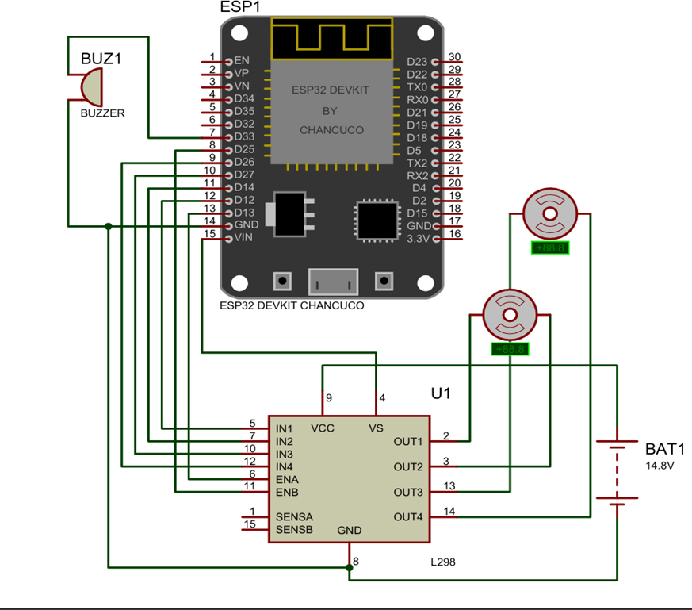
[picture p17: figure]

Figure C.1 — Full circuit schematic: ESP32, L298 motor driver, motors, and battery pack

## Appendix D: Programming Code Listing

The code consists of three logical parts running on the ESP32 board: Bluetooth command reception, motor driver control, and buzzer feedback. This code controls the movement of the sumo robot using Bluetooth communication. The ESP32 receives commands from a Bluetooth joystick app to determine the robot's direction and speed. Based on the received data, the motor driver controls the left and right motors to move forward, backward, or turn. Additionally, a buzzer is activated to provide audio feedback when a specific command is received, confirming successful communication.

#include "BluetoothSerial.h"

BluetoothSerial SerialBT;

// ---------- PIN MAPPING ----------const int ENA = 13;
const int IN1 = 12;
const int IN2 = 14;
const int IN3 = 27;
const int IN4 = 26;
const int ENB = 25;
const int buzzer = 33; // Buzzer Pin

// ---------- SETUP ----------
void setup() {
Serial.begin(115200);
SerialBT.begin("Jason_Joystick");

pinMode(ENA, OUTPUT);
pinMode(IN1, OUTPUT);
pinMode(IN2, OUTPUT);
pinMode(IN3, OUTPUT);
pinMode(IN4, OUTPUT);
pinMode(ENB, OUTPUT);
pinMode(buzzer, OUTPUT);

// Startup Beep
tone(buzzer, 2500, 200);
}

// ---------- MAIN LOOP ----------
void loop() {
if (SerialBT.available()) {
String data = SerialBT.readStringUntil('\n'); data.trim();
data.toUpperCase();

// ----- BUZZER COMMAND -----if (data.indexOf('Y') > -1) {

tone(buzzer, 2500, 500);
}

if (data.length() >= 6) {
char driveDir = data[0];
int driveSpeed = data.substring(1, 3).toInt(); char turnDir = data[3];
int turnAmount = data.substring(4, 6).toInt();

int maxSpeed = 255;
int drivePWM = map(driveSpeed, 0, 99, 0, maxSpeed); int turnPWM = map(turnAmount, 0, 99, 0, maxSpeed);

int leftSpeed, rightSpeed;

if (driveSpeed < 10 && turnAmount > 10) { if (turnDir == 'R') {
setDirections('B', 'F');
leftSpeed = turnPWM;
rightSpeed = turnPWM;
} else {
setDirections('F', 'B');
leftSpeed = turnPWM;
rightSpeed = turnPWM;
}
}
else {
char actualDir = (driveDir == 'F') ? 'B' : 'F'; setDirections(actualDir, actualDir);

if (turnDir == 'L') {
leftSpeed = drivePWM;
rightSpeed = drivePWM - turnPWM; } else {
leftSpeed = drivePWM - turnPWM; rightSpeed = drivePWM;
}
}

analogWrite(ENA, constrain(leftSpeed, 0, maxSpeed)); analogWrite(ENB, constrain(rightSpeed, 0, maxSpeed));

if (driveSpeed == 0 && turnAmount == 0) stopMotors();
}
}
}

// ---------- MOTOR DIRECTION ----------void setDirections(char motLeft, char motRight) { if (motLeft == 'F') {
digitalWrite(IN1, HIGH);
digitalWrite(IN2, LOW);
} else {
digitalWrite(IN1, LOW);
digitalWrite(IN2, HIGH);
}

if (motRight == 'F') {
digitalWrite(IN3, LOW);
digitalWrite(IN4, HIGH);
} else {
digitalWrite(IN3, HIGH);
digitalWrite(IN4, LOW);
}
}

// ---------- STOP MOTORS ----------void stopMotors() {
digitalWrite(IN1, LOW);
digitalWrite(IN2, LOW);
digitalWrite(IN3, LOW);
digitalWrite(IN4, LOW);
analogWrite(ENA, 0);
analogWrite(ENB, 0);
}

## Appendix E: Main Datasheets

The following sources and datasheets were used during the design and calculation process:

- Journal: International Journal of Innovations in Engineering Research and Technology (IJIERT), Volume 2, Issue 6, June 2015, Novateur Publications, Maharashtra, India.
- L298N Motor Driver datasheet — handsontec.com
- ESP32 datasheet — Espressif Systems documentation

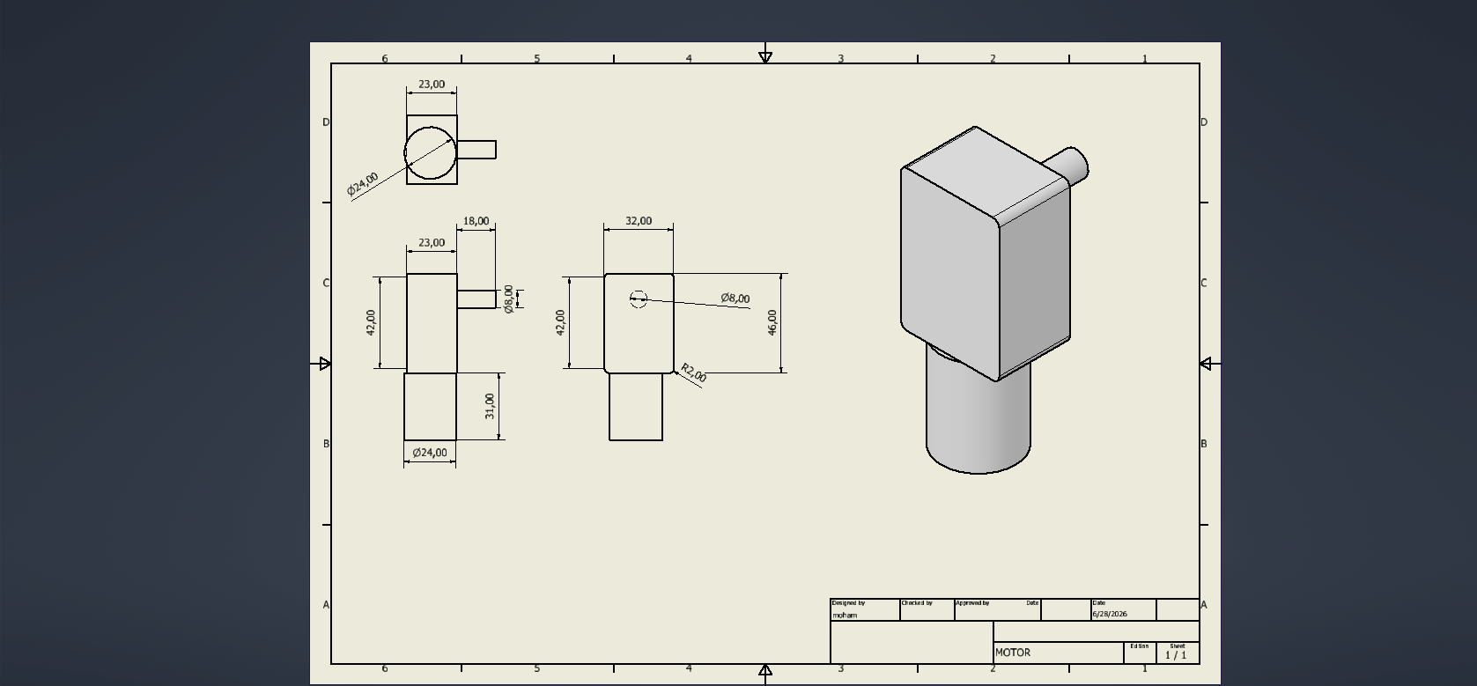
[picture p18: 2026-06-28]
images/MOTOR.png

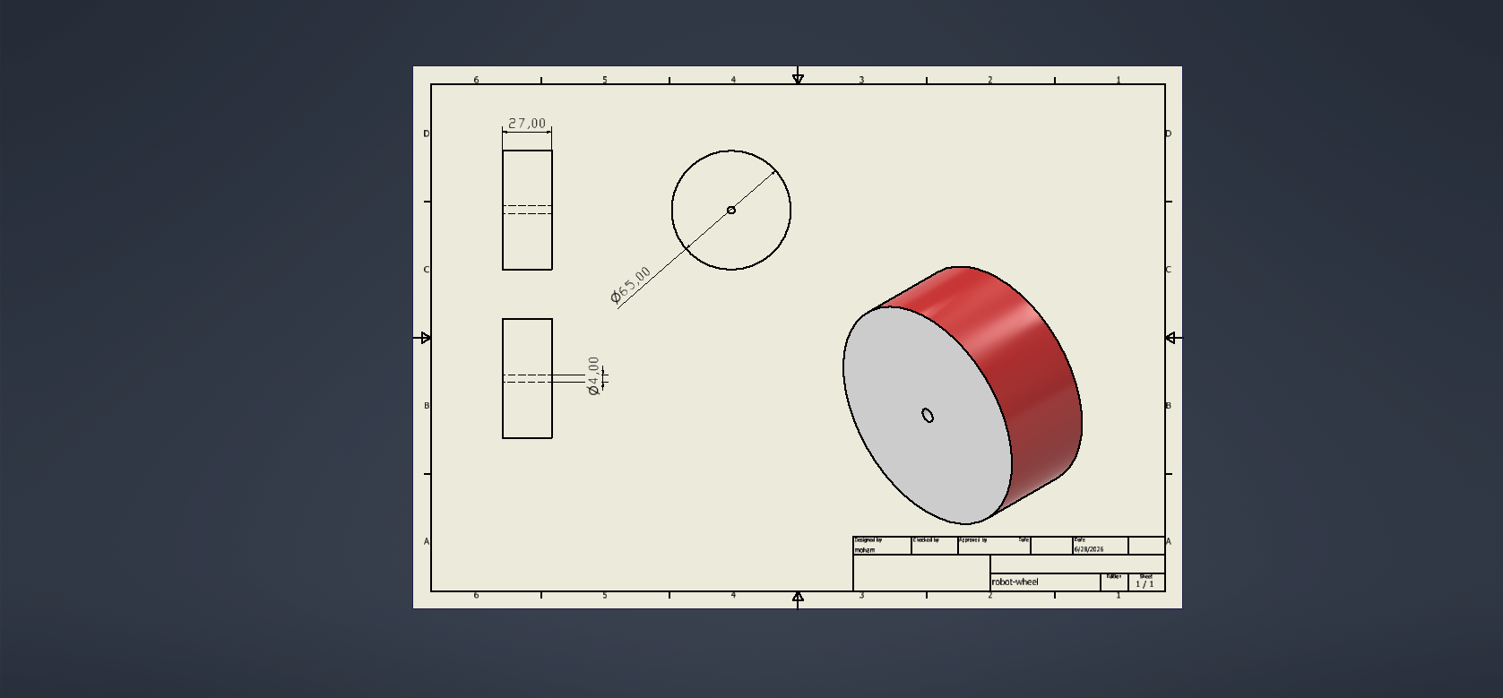
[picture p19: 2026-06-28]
images/robot-wheel.png

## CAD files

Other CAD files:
cad/Sumo-bot-assembly-drawing.dwg
cad/sumo-robot.dwg
cad/MOTOR.dwg
cad/robot-wheel.dwg
cad/MOTOR.ipt
cad/robot-wheel.ipt
cad/sumo-robot-body.ipt

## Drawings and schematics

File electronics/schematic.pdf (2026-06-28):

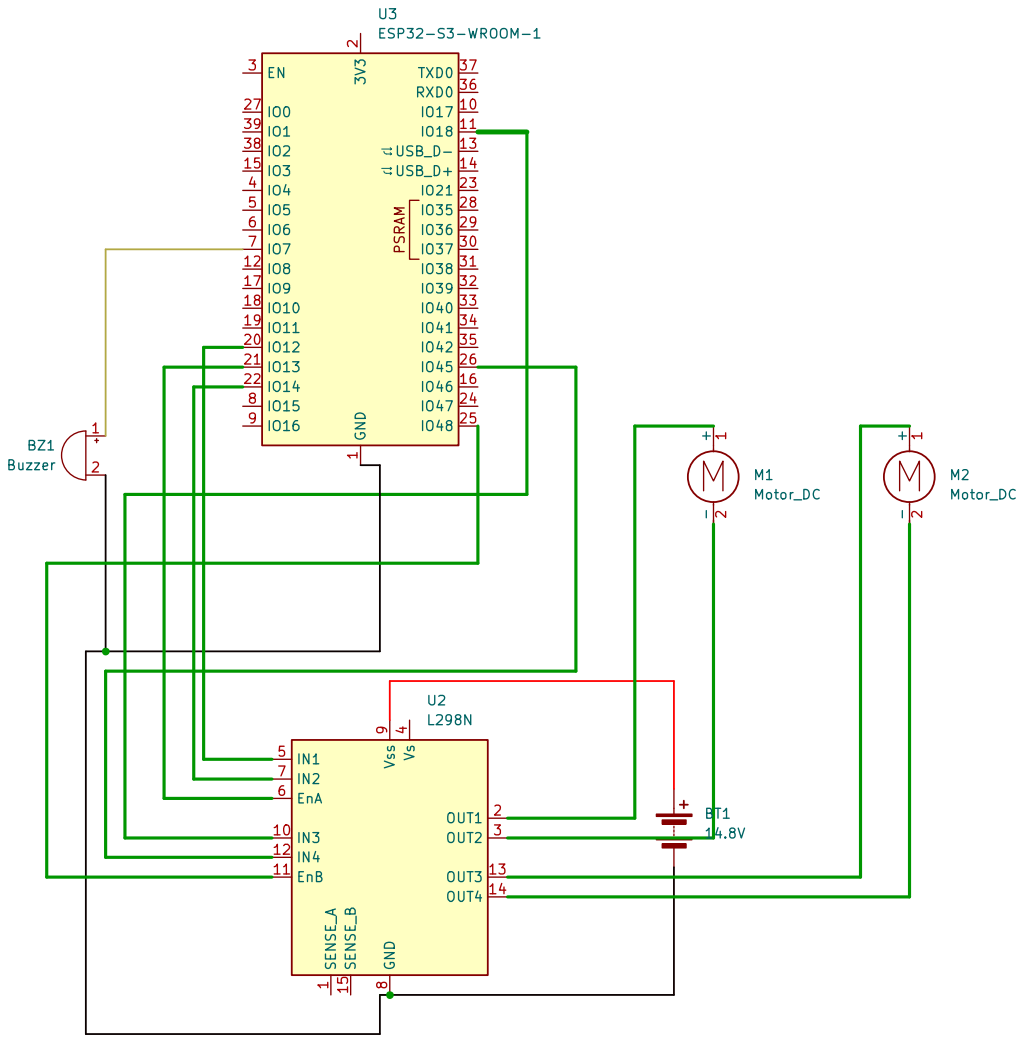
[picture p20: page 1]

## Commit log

2026-06-28 Create Cad folder
2026-06-28 Create cad directory
2026-06-28 added the assembly cad pic
2026-06-28 added the cad parts and assembly
    [MOTOR 2.ipt, intro 2 robot.ipt, robot wheel.ipt]
2026-06-28 added assembly dwg
    [Sumo-bot-assembly-drawing.dwg]
2026-06-28 added assembly dwg pic
2026-06-28 added wheel dwg
    [robot-wheel.dwg]
2026-06-28 added wheel pic
2026-06-28 add motor dwg
    [MOTOR.dwg]
2026-06-28 added motor pic
2026-06-28 added robot body dwg
    [sumo-robot.dwg]
2026-06-28 Rename intro 2 robot.ipt to sumo-robot-body.ipt
    [sumo-robot-body.ipt]
2026-06-28 Rename robot wheel.ipt to robot-wheel.ipt
    [robot-wheel.ipt]
2026-06-28 Rename MOTOR 2.ipt to MOTOR.ipt
    [MOTOR.ipt]
2026-06-28 added wiring
